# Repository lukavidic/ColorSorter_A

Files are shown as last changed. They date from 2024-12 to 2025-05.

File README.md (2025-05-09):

# 🎨 Color Sorter

## Projekat iz predmeta Mikrokontrolerski sistemi

**ColorSorter** je pametni sistem za automatsko razvrstavanje pločica po bojama. Projekat je razvijen u okviru predmeta *Mikrokontrolerski sistemi* i koristi:
- senzor boja
- servo motor za upravljanje mehanizmom sortiranja
- Wi-Fi modul za bežičnu komunikaciju

## Cilj projekta

Cilj je omogućiti **brzo, precizno i pametno sortiranje pločica** uz real-time komunikaciju i nadzor. Sistem je osmišljen tako da može raditi autonomno, kao i pod nadzorom korisnika putem aplikacije. Sve zahtjeve možete pogledati na **Wiki** stranici - [O projektu](https://github.com/lukavidic/ColorSorter_A/wiki/2.-O-projektu) kao i [dostupne i potrebne komponente](https://github.com/lukavidic/ColorSorter_A/wiki/3.-Dostupne-i-potrebne-komponente).

---

## Realizacija projekta

Razvoj sistema je tekao kroz sledeće faze:

1.  **Kreiranje električne šeme**
   
    Na samom početku kreirana je električna šema, koja prikazuje sve povezane komponente i njihovu funkcionalnu ulogu u realizaciji ovog projekta.
    Detalje možete pronaći na **Wiki** stranici – [Projektovanje električne šeme u alatu KiCAD](https://github.com/lukavidic/ColorSorter_A/wiki/4.-Projektovanje-elektri%C4%8Dne-%C5%A1eme-u-alatu-KiCAD).

2.  **Izrada PCB-a**
   
    Na osnovu električne šeme, dizajnirana je štampana ploča (PCB) koja omogućava stabilno napajanje i povezivanje svih perifernih komponenti.
    PCB sadrži:

      - Mikrokontroler PIC24FJ64GA702 kao centralnu upravljačku jedinicu

      - Pasivne komponente (otpornici, kondenzatori)
  
      - Regulatore napona
  
      - Konektore i pinove za povezivanje sa eksternim uređajima kao što su senzor boja, servo motor te WiFi modul
    
    Više o dizajnu ploče dostupno je na **Wiki** stranici – [Projektovanje PCB-a u alatu KiCAD](https://github.com/lukavidic/ColorSorter_A/wiki/4.-Projektovanje-elektri%C4%8Dne-%C5%A1eme-u-alatu-KiCAD).

3.  **Programiranje mikrokontrolera**
   
    Nakon hardverske realizacije, implementiran je kod za rad uređaja – uključujući očitavanje boja, kontrolu motora i Wi-Fi komunikaciju, čiju dokumentaciju kompletnog koda možete pronaći na **Wiki** stranici - [Programiranje mikrokontrolera](https://github.com/lukavidic/ColorSorter_A/wiki/6.-Programiranje-mikrokontrolera).

4. **Izrada aplikacije**

   Nakon uspješnog programiranja mikrokontrolerske pločice, pristupili smo razvoju desktop aplikacije koja omogućava nadzor i upravljanje procesom razvrstavanja boja. Aplikacija komunicira sa uređajem putem WiFi veze i omogućava korisniku da prati status sistema u realnom vremenu, šalje komande za pokretanje i resetovanje, te definiše pravila sortiranja po bojama. O zahtjevima aplikacije možete pogledati na **Wiki** stranici - [Firmware i aplikacija](https://github.com/lukavidic/ColorSorter_A/wiki/7.-Firmware-i-aplikacija).

5.  **Testiranje i kalibracija**
   
    Sistem je prolazio kroz više faza testiranja kako bi se obezbijedila tačnost u detekciji boja i pravilno sortiranje. Kratak pogled u testiranje komponenata možete pronaći na **Wiki** stranici - [Testiranje rada komponenata](https://github.com/lukavidic/ColorSorter_A/wiki/7.-Testiranje-rada-komponenata).

colorsorter

---

## Autori
- Ana Vulin  
- Anđela Savičić  
- Luka Zeljko

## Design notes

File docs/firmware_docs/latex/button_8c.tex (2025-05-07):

\doxysection{button/button.c File Reference}
\hypertarget{button_8c}{}\label{button_8c}\index{button/button.c@{button/button.c}}

Button module source file.  

{\ttfamily \#include "{}button.\+h"{}}\newline
{\ttfamily \#include "{}../led/led.\+h"{}}\newline
{\ttfamily \#include "{}../servo/servo.\+h"{}}\newline
{\ttfamily \#include "{}../color\+\_\+sensor/color\+\_\+sensor.\+h"{}}\newline
{\ttfamily \#include "{}../inc/inc.\+h"{}}\newline
\doxysubsubsection*{Functions}
\begin{DoxyCompactItemize}
\item 
void \mbox{\hyperlink{button_8c_a681470fea7c7eaa67094df3e5567a8f7}{button\+\_\+init}} ()
\begin{DoxyCompactList}\small\item\em Initializes the button and sets up interrupt configuration. \end{DoxyCompactList}\item 
void \mbox{\hyperlink{button_8c_aab3a22f4fca32e3600be53c5cd5cdc55}{init\+Prekidi}} ()
\begin{DoxyCompactList}\small\item\em Initializes interrupts for the button. \end{DoxyCompactList}\item 
void \mbox{\hyperlink{button_8c_a226557d5e42f7e29ddaff30606138459}{\+\_\+\+\_\+attribute\+\_\+\+\_\+}} ((interrupt, no\+\_\+auto\+\_\+psv))
\begin{DoxyCompactList}\small\item\em Interrupt service routine for I2\+C1 slave interrupt. \end{DoxyCompactList}\end{DoxyCompactItemize}
\doxysubsubsection*{Variables}
\begin{DoxyCompactItemize}
\item 
int \mbox{\hyperlink{button_8c_aac274e9c06b25faa040b6ba219fc2e75}{reset\+\_\+counter}} = 1
\item 
volatile int \mbox{\hyperlink{button_8c_a81abebcb507939407ceaeb9007b656bc}{press\+\_\+counter}} = 1
\end{DoxyCompactItemize}

\doxysubsection{Detailed Description}
Button module source file. 

File containing definitions of functions decleared in \doxylink{button_8h}{button.\+h} 

\doxysubsection{Function Documentation}
\Hypertarget{button_8c_a226557d5e42f7e29ddaff30606138459}\index{button.c@{button.c}!\_\_attribute\_\_@{\_\_attribute\_\_}}
\index{\_\_attribute\_\_@{\_\_attribute\_\_}!button.c@{button.c}}
\doxysubsubsection{\texorpdfstring{\_\_attribute\_\_()}{\_\_attribute\_\_()}}
{\footnotesize\ttfamily \label{button_8c_a226557d5e42f7e29ddaff30606138459} 
void \+\_\+\+\_\+attribute\+\_\+\+\_\+ (\begin{DoxyParamCaption}\item[{(interrupt, no\+\_\+auto\+\_\+psv)}]{}{}\end{DoxyParamCaption})}

Interrupt service routine for I2\+C1 slave interrupt. 

INT1 interrupt handler (button press).

This interrupt handler is called when an I2\+C1 slave mode interrupt occurs. It invokes the user-\/defined ISR set by the {\ttfamily i2c1\+\_\+driver\+\_\+set\+Slave\+I2c\+ISR} function. \Hypertarget{button_8c_a681470fea7c7eaa67094df3e5567a8f7}\index{button.c@{button.c}!button\_init@{button\_init}}
\index{button\_init@{button\_init}!button.c@{button.c}}
\doxysubsubsection{\texorpdfstring{button\_init()}{button\_init()}}
{\footnotesize\ttfamily \label{button_8c_a681470fea7c7eaa67094df3e5567a8f7} 
void button\+\_\+init (\begin{DoxyParamCaption}{}{}\end{DoxyParamCaption})}

Initializes the button and sets up interrupt configuration. 

This function configures pin RB5 as an input and calls the function to initialize interrupts. \Hypertarget{button_8c_aab3a22f4fca32e3600be53c5cd5cdc55}\index{button.c@{button.c}!initPrekidi@{initPrekidi}}
\index{initPrekidi@{initPrekidi}!button.c@{button.c}}
\doxysubsubsection{\texorpdfstring{initPrekidi()}{initPrekidi()}}
{\footnotesize\ttfamily \label{button_8c_aab3a22f4fca32e3600be53c5cd5cdc55} 
void init\+Prekidi (\begin{DoxyParamCaption}{}{}\end{DoxyParamCaption})}

Initializes interrupts for the button. 

This function sets up the parameters for INT1 interrupt, enables the interrupt on falling edge, and enables global interrupts. 

\doxysubsection{Variable Documentation}
\Hypertarget{button_8c_a81abebcb507939407ceaeb9007b656bc}\index{button.c@{button.c}!press\_counter@{press\_counter}}
\index{press\_counter@{press\_counter}!button.c@{button.c}}
\doxysubsubsection{\texorpdfstring{press\_counter}{press\_counter}}
{\footnotesize\ttfamily \label{button_8c_a81abebcb507939407ceaeb9007b656bc} 
volatile int press\+\_\+counter = 1}

\Hypertarget{button_8c_aac274e9c06b25faa040b6ba219fc2e75}\index{button.c@{button.c}!reset\_counter@{reset\_counter}}
\index{reset\_counter@{reset\_counter}!button.c@{button.c}}
\doxysubsubsection{\texorpdfstring{reset\_counter}{reset\_counter}}
{\footnotesize\ttfamily \label{button_8c_aac274e9c06b25faa040b6ba219fc2e75} 
int reset\+\_\+counter = 1}

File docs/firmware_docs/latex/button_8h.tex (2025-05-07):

\doxysection{button/button.h File Reference}
\hypertarget{button_8h}{}\label{button_8h}\index{button/button.h@{button/button.h}}

BUTTON header file.  

{\ttfamily \#include "{}../inc/inc.\+h"{}}\newline
\doxysubsubsection*{Functions}
\begin{DoxyCompactItemize}
\item 
void \mbox{\hyperlink{button_8h_a681470fea7c7eaa67094df3e5567a8f7}{button\+\_\+init}} ()
\begin{DoxyCompactList}\small\item\em Initializes the button and sets up interrupt configuration. \end{DoxyCompactList}\item 
void \mbox{\hyperlink{button_8h_aab3a22f4fca32e3600be53c5cd5cdc55}{init\+Prekidi}} ()
\begin{DoxyCompactList}\small\item\em Initializes interrupts for the button. \end{DoxyCompactList}\item 
void \mbox{\hyperlink{button_8h_a806ff639c7979669bd17a40fc3986611}{\+\_\+\+\_\+attribute\+\_\+\+\_\+}} ((interrupt, no\+\_\+auto\+\_\+psv)) \+\_\+\+INT1\+Interrupt(void)
\begin{DoxyCompactList}\small\item\em INT1 interrupt handler (button press). \end{DoxyCompactList}\end{DoxyCompactItemize}
\doxysubsubsection*{Variables}
\begin{DoxyCompactItemize}
\item 
volatile int \mbox{\hyperlink{button_8h_a81abebcb507939407ceaeb9007b656bc}{press\+\_\+counter}}
\item 
int \mbox{\hyperlink{button_8h_aac274e9c06b25faa040b6ba219fc2e75}{reset\+\_\+counter}}
\end{DoxyCompactItemize}

\doxysubsection{Detailed Description}
BUTTON header file. 

This file contains function definitions for BUTTON control 

\doxysubsection{Function Documentation}
\Hypertarget{button_8h_a806ff639c7979669bd17a40fc3986611}\index{button.h@{button.h}!\_\_attribute\_\_@{\_\_attribute\_\_}}
\index{\_\_attribute\_\_@{\_\_attribute\_\_}!button.h@{button.h}}
\doxysubsubsection{\texorpdfstring{\_\_attribute\_\_()}{\_\_attribute\_\_()}}
{\footnotesize\ttfamily \label{button_8h_a806ff639c7979669bd17a40fc3986611} 
void \+\_\+\+\_\+attribute\+\_\+\+\_\+ (\begin{DoxyParamCaption}\item[{(interrupt, no\+\_\+auto\+\_\+psv)}]{}{}\end{DoxyParamCaption})}

INT1 interrupt handler (button press). 

This function is called when the button connected to INT1 is pressed. It increments the press counter and toggles the system state (turns LED on/off, centers the servo, and sets RGB color) based on the number of presses.

INT1 interrupt handler (button press).

This interrupt handler is called when an I2\+C1 slave mode interrupt occurs. It invokes the user-\/defined ISR set by the {\ttfamily i2c1\+\_\+driver\+\_\+set\+Slave\+I2c\+ISR} function.

INT1 interrupt handler (button press).

Interrupt service routine for I2\+C1 slave interrupt.

This interrupt handler is called when an I2\+C1 master mode interrupt occurs. It invokes the user-\/defined ISR set by the {\ttfamily i2c1\+\_\+driver\+\_\+set\+Master\+I2c\+ISR} function.

This interrupt handler is called when an I2\+C1 slave mode interrupt occurs. It invokes the user-\/defined ISR set by the {\ttfamily i2c1\+\_\+driver\+\_\+set\+Slave\+I2c\+ISR} function. \Hypertarget{button_8h_a681470fea7c7eaa67094df3e5567a8f7}\index{button.h@{button.h}!button\_init@{button\_init}}
\index{button\_init@{button\_init}!button.h@{button.h}}
\doxysubsubsection{\texorpdfstring{button\_init()}{button\_init()}}
{\footnotesize\ttfamily \label{button_8h_a681470fea7c7eaa67094df3e5567a8f7} 
void button\+\_\+init (\begin{DoxyParamCaption}{}{}\end{DoxyParamCaption})}

Initializes the button and sets up interrupt configuration. 

This function configures pin RB5 as an input and calls the function to initialize interrupts. \Hypertarget{button_8h_aab3a22f4fca32e3600be53c5cd5cdc55}\index{button.h@{button.h}!initPrekidi@{initPrekidi}}
\index{initPrekidi@{initPrekidi}!button.h@{button.h}}
\doxysubsubsection{\texorpdfstring{initPrekidi()}{initPrekidi()}}
{\footnotesize\ttfamily \label{button_8h_aab3a22f4fca32e3600be53c5cd5cdc55} 
void init\+Prekidi (\begin{DoxyParamCaption}{}{}\end{DoxyParamCaption})}

Initializes interrupts for the button. 

This function sets up the parameters for INT1 interrupt, enables the interrupt on falling edge, and enables global interrupts. 

\doxysubsection{Variable Documentation}
\Hypertarget{button_8h_a81abebcb507939407ceaeb9007b656bc}\index{button.h@{button.h}!press\_counter@{press\_counter}}
\index{press\_counter@{press\_counter}!button.h@{button.h}}
\doxysubsubsection{\texorpdfstring{press\_counter}{press\_counter}}
{\footnotesize\ttfamily \label{button_8h_a81abebcb507939407ceaeb9007b656bc} 
volatile int press\+\_\+counter\hspace{0.3cm}{\ttfamily [extern]}}

\Hypertarget{button_8h_aac274e9c06b25faa040b6ba219fc2e75}\index{button.h@{button.h}!reset\_counter@{reset\_counter}}
\index{reset\_counter@{reset\_counter}!button.h@{button.h}}
\doxysubsubsection{\texorpdfstring{reset\_counter}{reset\_counter}}
{\footnotesize\ttfamily \label{button_8h_aac274e9c06b25faa040b6ba219fc2e75} 
int reset\+\_\+counter\hspace{0.3cm}{\ttfamily [extern]}}

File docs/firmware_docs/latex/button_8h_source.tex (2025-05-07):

\doxysection{button.\+h}
\hypertarget{button_8h_source}{}\label{button_8h_source}\index{button/button.h@{button/button.h}}
\mbox{\hyperlink{button_8h}{Go to the documentation of this file.}}
\begin{DoxyCode}{0}
\DoxyCodeLine{00001\ }
\DoxyCodeLine{00007\ \textcolor{preprocessor}{\#ifndef\ BUTTON\_H}}
\DoxyCodeLine{00008\ }
\DoxyCodeLine{00009\ \textcolor{preprocessor}{\#define\ BUTTON\_H}}
\DoxyCodeLine{00010\ }
\DoxyCodeLine{00011\ \textcolor{preprocessor}{\#include\ "{}\mbox{\hyperlink{inc_8h}{../inc/inc.h}}"{}}}
\DoxyCodeLine{00012\ }
\DoxyCodeLine{00013\ \textcolor{comment}{//\ External\ variable\ that\ counts\ button\ presses.}}
\DoxyCodeLine{00014\ \textcolor{keyword}{extern}\ \textcolor{keyword}{volatile}\ \textcolor{keywordtype}{int}\ \mbox{\hyperlink{button_8c_a81abebcb507939407ceaeb9007b656bc}{press\_counter}};}
\DoxyCodeLine{00015\ }
\DoxyCodeLine{00016\ \textcolor{comment}{//\ External\ variable\ that\ controls\ system\ reset.}}
\DoxyCodeLine{00017\ \textcolor{keyword}{extern}\ \textcolor{keywordtype}{int}\ \mbox{\hyperlink{button_8c_aac274e9c06b25faa040b6ba219fc2e75}{reset\_counter}};}
\DoxyCodeLine{00018\ }
\DoxyCodeLine{00025\ \textcolor{keywordtype}{void}\ \mbox{\hyperlink{button_8h_a681470fea7c7eaa67094df3e5567a8f7}{button\_init}}();}
\DoxyCodeLine{00032\ \textcolor{keywordtype}{void}\ \mbox{\hyperlink{button_8h_aab3a22f4fca32e3600be53c5cd5cdc55}{initPrekidi}}();}
\DoxyCodeLine{00040\ \textcolor{keywordtype}{void}\ \mbox{\hyperlink{button_8h_a806ff639c7979669bd17a40fc3986611}{\_\_attribute\_\_}}((interrupt,\ no\_auto\_psv))\ \_INT1Interrupt(\textcolor{keywordtype}{void});}
\DoxyCodeLine{00041\ }
\DoxyCodeLine{00042\ \textcolor{preprocessor}{\#endif}}

\end{DoxyCode}

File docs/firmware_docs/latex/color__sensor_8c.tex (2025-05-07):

\doxysection{color\+\_\+sensor/color\+\_\+sensor.c File Reference}
\hypertarget{color__sensor_8c}{}\label{color__sensor_8c}\index{color\_sensor/color\_sensor.c@{color\_sensor/color\_sensor.c}}

\doxylink{structColor}{Color} sensor module source file.  

{\ttfamily \#include "{}color\+\_\+sensor.\+h"{}}\newline
{\ttfamily \#include "{}../led/led.\+h"{}}\newline
{\ttfamily \#include "{}../inc/inc.\+h"{}}\newline
{\ttfamily \#include "{}../color\+\_\+sensor/i2c\+\_\+simple\+\_\+master.\+h"{}}\newline
{\ttfamily \#include "{}../color\+\_\+sensor/i2c\+\_\+master.\+h"{}}\newline
{\ttfamily \#include "{}xc.\+h"{}}\newline
{\ttfamily \#include $<$stdio.\+h$>$}\newline
{\ttfamily \#include $<$math.\+h$>$}\newline
{\ttfamily \#include $<$stdint.\+h$>$}\newline
\doxysubsubsection*{Data Structures}
\begin{DoxyCompactItemize}
\item 
struct \mbox{\hyperlink{structColor}{Color}}
\end{DoxyCompactItemize}
\doxysubsubsection*{Functions}
\begin{DoxyCompactItemize}
\item 
char \texorpdfstring{$\ast$}{*} \mbox{\hyperlink{color__sensor_8c_a9fa725f2640f9efd473fc7a5f2de92dc}{detect\+\_\+color}} ()
\begin{DoxyCompactList}\small\item\em Detects the color based on sensor readings. \end{DoxyCompactList}\item 
void \mbox{\hyperlink{color__sensor_8c_a30da27c967c427811646a5a6f66f495f}{WS2812\+\_\+\+Send\+\_\+\+Byte}} (uint8\+\_\+t byte)
\begin{DoxyCompactList}\small\item\em Sends a single byte of data to the WS2812 RGB LED. \end{DoxyCompactList}\item 
void \mbox{\hyperlink{color__sensor_8c_a938d9076304a30229d0cff9510c6b0de}{WS2812\+\_\+\+Set\+Color}} (uint8\+\_\+t red, uint8\+\_\+t green, uint8\+\_\+t blue)
\begin{DoxyCompactList}\small\item\em Sets the color of the WS2812 RGB LED. \end{DoxyCompactList}\item 
uint16\+\_\+t \mbox{\hyperlink{color__sensor_8c_a053b418e905501066d9d10d143bde94a}{VEML3328\+\_\+read\+Config}} (uint16\+\_\+t r)
\begin{DoxyCompactList}\small\item\em Reads the configuration register of the VEML3328 color sensor. \end{DoxyCompactList}\item 
char \texorpdfstring{$\ast$}{*} \mbox{\hyperlink{color__sensor_8c_a9bafee1f49378aa30e64fec0a857a6b4}{read\+\_\+colors}} ()
\begin{DoxyCompactList}\small\item\em Reads the color data from the VEML3328 sensor and detects the closest matching color. \end{DoxyCompactList}\item 
float \mbox{\hyperlink{color__sensor_8c_a1e56582afed332aa1260fc2785c7777e}{color\+\_\+distance}} (uint16\+\_\+t r1, uint16\+\_\+t g1, uint16\+\_\+t b1, uint16\+\_\+t r2, uint16\+\_\+t g2, uint16\+\_\+t b2)
\begin{DoxyCompactList}\small\item\em Calculates the Euclidean distance between two RGB colors. \end{DoxyCompactList}\end{DoxyCompactItemize}
\doxysubsubsection*{Variables}
\begin{DoxyCompactItemize}
\item 
uint16\+\_\+t \mbox{\hyperlink{color__sensor_8c_aa4dbd934c1f532f057c7016fc46c17d8}{sensor\+\_\+value\+\_\+clear}}
\item 
uint16\+\_\+t \mbox{\hyperlink{color__sensor_8c_a40af162a563cdee76bbc32221b1700f6}{sensor\+\_\+value\+\_\+red}}
\item 
uint16\+\_\+t \mbox{\hyperlink{color__sensor_8c_ad72744df2efce619a151cdd8f6a28aeb}{sensor\+\_\+value\+\_\+green}}
\item 
uint16\+\_\+t \mbox{\hyperlink{color__sensor_8c_ac8d4dfdb5c4ec07d415bb45a1f8e4d00}{sensor\+\_\+value\+\_\+blue}}
\item 
const \mbox{\hyperlink{structColor}{Color}} \mbox{\hyperlink{color__sensor_8c_a0e450f8f554764fb50c75197d16a7c9f}{colors}} \mbox{[}$\,$\mbox{]}
\end{DoxyCompactItemize}

\doxysubsection{Detailed Description}
\doxylink{structColor}{Color} sensor module source file. 

This file contains definitions of functions decleared in \doxylink{color__sensor_8h}{color\+\_\+sensor.\+h} 

\doxysubsection{Function Documentation}
\Hypertarget{color__sensor_8c_a1e56582afed332aa1260fc2785c7777e}\index{color\_sensor.c@{color\_sensor.c}!color\_distance@{color\_distance}}
\index{color\_distance@{color\_distance}!color\_sensor.c@{color\_sensor.c}}
\doxysubsubsection{\texorpdfstring{color\_distance()}{color\_distance()}}
{\footnotesize\ttfamily \label{color__sensor_8c_a1e56582afed332aa1260fc2785c7777e} 
float color\+\_\+distance (\begin{DoxyParamCaption}\item[{uint16\+\_\+t}]{r1}{, }\item[{uint16\+\_\+t}]{g1}{, }\item[{uint16\+\_\+t}]{b1}{, }\item[{uint16\+\_\+t}]{r2}{, }\item[{uint16\+\_\+t}]{g2}{, }\item[{uint16\+\_\+t}]{b2}{}\end{DoxyParamCaption})}

Calculates the Euclidean distance between two RGB colors. 

This function calculates the Euclidean distance between two colors in the RGB color space. The smaller the distance, the closer the two colors are.

\begin{DoxyParams}{Parameters}
{\em r1} & The red component of the first color. \\
\hline
{\em g1} & The green component of the first color. \\
\hline
{\em b1} & The blue component of the first color. \\
\hline
{\em r2} & The red component of the second color. \\
\hline
{\em g2} & The green component of the second color. \\
\hline
{\em b2} & The blue component of the second color.\\
\hline
\end{DoxyParams}
\begin{DoxyReturn}{Returns}
The Euclidean distance between the two colors. 
\end{DoxyReturn}
\Hypertarget{color__sensor_8c_a9fa725f2640f9efd473fc7a5f2de92dc}\index{color\_sensor.c@{color\_sensor.c}!detect\_color@{detect\_color}}
\index{detect\_color@{detect\_color}!color\_sensor.c@{color\_sensor.c}}
\doxysubsubsection{\texorpdfstring{detect\_color()}{detect\_color()}}
{\footnotesize\ttfamily \label{color__sensor_8c_a9fa725f2640f9efd473fc7a5f2de92dc} 
char \texorpdfstring{$\ast$}{*} detect\+\_\+color (\begin{DoxyParamCaption}{}{}\end{DoxyParamCaption})}

Detects the color based on sensor readings. 

This function compares the RGB values of the detected color from the sensor to a list of predefined colors and calculates the Euclidean distance to find the closest match.

\begin{DoxyReturn}{Returns}
The name of the closest matching color as a string. 
\end{DoxyReturn}
\Hypertarget{color__sensor_8c_a9bafee1f49378aa30e64fec0a857a6b4}\index{color\_sensor.c@{color\_sensor.c}!read\_colors@{read\_colors}}
\index{read\_colors@{read\_colors}!color\_sensor.c@{color\_sensor.c}}
\doxysubsubsection{\texorpdfstring{read\_colors()}{read\_colors()}}
{\footnotesize\ttfamily \label{color__sensor_8c_a9bafee1f49378aa30e64fec0a857a6b4} 
char \texorpdfstring{$\ast$}{*} read\+\_\+colors (\begin{DoxyParamCaption}{}{}\end{DoxyParamCaption})}

Reads the color data from the VEML3328 sensor and detects the closest matching color. 

This function collects multiple color samples (red, green, blue) from the VEML3328 sensor, averages the readings, and uses the {\ttfamily detect\+\_\+color} function to identify the closest matching color.

\begin{DoxyReturn}{Returns}
The name of the closest matching color as a string. 
\end{DoxyReturn}
\Hypertarget{color__sensor_8c_a053b418e905501066d9d10d143bde94a}\index{color\_sensor.c@{color\_sensor.c}!VEML3328\_readConfig@{VEML3328\_readConfig}}
\index{VEML3328\_readConfig@{VEML3328\_readConfig}!color\_sensor.c@{color\_sensor.c}}
\doxysubsubsection{\texorpdfstring{VEML3328\_readConfig()}{VEML3328\_readConfig()}}
{\footnotesize\ttfamily \label{color__sensor_8c_a053b418e905501066d9d10d143bde94a} 
uint16\+\_\+t VEML3328\+\_\+read\+Config (\begin{DoxyParamCaption}\item[{uint16\+\_\+t}]{r}{}\end{DoxyParamCaption})}

Reads the configuration register of the VEML3328 color sensor. 

This function reads a 16-\/bit value from a specified register on the VEML3328 sensor over I2C.

\begin{DoxyParams}{Parameters}
{\em r} & The register address to be read.\\
\hline
\end{DoxyParams}
\begin{DoxyReturn}{Returns}
The 16-\/bit value read from the specified register. 
\end{DoxyReturn}
\Hypertarget{color__sensor_8c_a30da27c967c427811646a5a6f66f495f}\index{color\_sensor.c@{color\_sensor.c}!WS2812\_Send\_Byte@{WS2812\_Send\_Byte}}
\index{WS2812\_Send\_Byte@{WS2812\_Send\_Byte}!color\_sensor.c@{color\_sensor.c}}
\doxysubsubsection{\texorpdfstring{WS2812\_Send\_Byte()}{WS2812\_Send\_Byte()}}
{\footnotesize\ttfamily \label{color__sensor_8c_a30da27c967c427811646a5a6f66f495f} 
void WS2812\+\_\+\+Send\+\_\+\+Byte (\begin{DoxyParamCaption}\item[{uint8\+\_\+t}]{byte}{}\end{DoxyParamCaption})}

Sends a single byte of data to the WS2812 RGB LED. 

This function sends a byte of data to the WS2812 LED over SPI, with each bit corresponding to a part of the LED data stream.

\begin{DoxyParams}{Parameters}
{\em byte} & The byte to be sent to the WS2812. \\
\hline
\end{DoxyParams}
\Hypertarget{color__sensor_8c_a938d9076304a30229d0cff9510c6b0de}\index{color\_sensor.c@{color\_sensor.c}!WS2812\_SetColor@{WS2812\_SetColor}}
\index{WS2812\_SetColor@{WS2812\_SetColor}!color\_sensor.c@{color\_sensor.c}}
\doxysubsubsection{\texorpdfstring{WS2812\_SetColor()}{WS2812\_SetColor()}}
{\footnotesize\ttfamily \label{color__sensor_8c_a938d9076304a30229d0cff9510c6b0de} 
void WS2812\+\_\+\+Set\+Color (\begin{DoxyParamCaption}\item[{uint8\+\_\+t}]{red}{, }\item[{uint8\+\_\+t}]{green}{, }\item[{uint8\+\_\+t}]{blue}{}\end{DoxyParamCaption})}

Sets the color of the WS2812 RGB LED. 

This function sends the color values for red, green, and blue to the WS2812 LED using SPI.

\begin{DoxyParams}{Parameters}
{\em red} & The red component of the color (0-\/255). \\
\hline
{\em green} & The green component of the color (0-\/255). \\
\hline
{\em blue} & The blue component of the color (0-\/255). \\
\hline
\end{DoxyParams}

\doxysubsection{Variable Documentation}
\Hypertarget{color__sensor_8c_a0e450f8f554764fb50c75197d16a7c9f}\index{color\_sensor.c@{color\_sensor.c}!colors@{colors}}
\index{colors@{colors}!color\_sensor.c@{color\_sensor.c}}
\doxysubsubsection{\texorpdfstring{colors}{colors}}
{\footnotesize\ttfamily \label{color__sensor_8c_a0e450f8f554764fb50c75197d16a7c9f} 
const \mbox{\hyperlink{structColor}{Color}} colors\mbox{[}$\,$\mbox{]}}

{\bfseries Initial value\+:}
\begin{DoxyCode}{0}
\DoxyCodeLine{=\ \{}
\DoxyCodeLine{\ \ \ \ \{\textcolor{stringliteral}{"{}ZELENA"{}},\ \ \ \ \ 6500,\ 29000,\ 28000\},}
\DoxyCodeLine{\ \ \ \ \{\textcolor{stringliteral}{"{}PLAVA"{}},\ \ \ \ \ \ 13800,\ 45100,\ 65500\},}
\DoxyCodeLine{\ \ \ \ \{\textcolor{stringliteral}{"{}CRVENA"{}},\ \ \ \ 40500,\ 21800,\ 24400\},}
\DoxyCodeLine{\ \ \ \ \{\textcolor{stringliteral}{"{}ZUTA"{}},\ \ \ \ \ \ 45000,\ 65535,\ 40500\},}
\DoxyCodeLine{\ \ \ \ \{\textcolor{stringliteral}{"{}NARANDZASTA"{}},40700,\ 18800,\ 14500\},}
\DoxyCodeLine{\ \ \ \ \{\textcolor{stringliteral}{"{}ROZA"{}},\ \ \ \ \ \ 34100,\ 20200,\ 29800\},}
\DoxyCodeLine{\ \ \ \ \{\textcolor{stringliteral}{"{}CRNA"{}},\ \ \ \ \ \ \ 6000,\ 12300,\ 16500\},}
\DoxyCodeLine{\ \ \ \ \{\textcolor{stringliteral}{"{}BIJELA"{}},\ \ \ \ 48900,\ 65535,\ 65535\},}
\DoxyCodeLine{\ \ \ \ \{\textcolor{stringliteral}{"{}NO"{}},\ \ \ \ \ \ \ \ \ 15700,\ \ 19000,\ \ 21000\},}
\DoxyCodeLine{\ \ \ \ \{\textcolor{stringliteral}{"{}OCRNA"{}},\ \ \ \ \ \ 7800,11800,16000\},\ }
\DoxyCodeLine{\ \ \ \ \{\textcolor{stringliteral}{"{}OBIJELA"{}},\ \ \ \ \ \ 30800,45900,63900\}\ }
\DoxyCodeLine{\}}

\end{DoxyCode}
\Hypertarget{color__sensor_8c_ac8d4dfdb5c4ec07d415bb45a1f8e4d00}\index{color\_sensor.c@{color\_sensor.c}!sensor\_value\_blue@{sensor\_value\_blue}}
\index{sensor\_value\_blue@{sensor\_value\_blue}!color\_sensor.c@{color\_sensor.c}}
\doxysubsubsection{\texorpdfstring{sensor\_value\_blue}{sensor\_value\_blue}}
{\footnotesize\ttfamily \label{color__sensor_8c_ac8d4dfdb5c4ec07d415bb45a1f8e4d00} 
uint16\+\_\+t sensor\+\_\+value\+\_\+blue}

\Hypertarget{color__sensor_8c_aa4dbd934c1f532f057c7016fc46c17d8}\index{color\_sensor.c@{color\_sensor.c}!sensor\_value\_clear@{sensor\_value\_clear}}
\index{sensor\_value\_clear@{sensor\_value\_clear}!color\_sensor.c@{color\_sensor.c}}
\doxysubsubsection{\texorpdfstring{sensor\_value\_clear}{sensor\_value\_clear}}
{\footnotesize\ttfamily \label{color__sensor_8c_aa4dbd934c1f532f057c7016fc46c17d8} 
uint16\+\_\+t sensor\+\_\+value\+\_\+clear}

\Hypertarget{color__sensor_8c_ad72744df2efce619a151cdd8f6a28aeb}\index{color\_sensor.c@{color\_sensor.c}!sensor\_value\_green@{sensor\_value\_green}}
\index{sensor\_value\_green@{sensor\_value\_green}!color\_sensor.c@{color\_sensor.c}}
\doxysubsubsection{\texorpdfstring{sensor\_value\_green}{sensor\_value\_green}}
{\footnotesize\ttfamily \label{color__sensor_8c_ad72744df2efce619a151cdd8f6a28aeb} 
uint16\+\_\+t sensor\+\_\+value\+\_\+green}

\Hypertarget{color__sensor_8c_a40af162a563cdee76bbc32221b1700f6}\index{color\_sensor.c@{color\_sensor.c}!sensor\_value\_red@{sensor\_value\_red}}
\index{sensor\_value\_red@{sensor\_value\_red}!color\_sensor.c@{color\_sensor.c}}
\doxysubsubsection{\texorpdfstring{sensor\_value\_red}{sensor\_value\_red}}
{\footnotesize\ttfamily \label{color__sensor_8c_a40af162a563cdee76bbc32221b1700f6} 
uint16\+\_\+t sensor\+\_\+value\+\_\+red}

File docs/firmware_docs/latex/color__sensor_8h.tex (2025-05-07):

\doxysection{color\+\_\+sensor/color\+\_\+sensor.h File Reference}
\hypertarget{color__sensor_8h}{}\label{color__sensor_8h}\index{color\_sensor/color\_sensor.h@{color\_sensor/color\_sensor.h}}

\doxylink{structColor}{Color} sensor module header file.  

{\ttfamily \#include "{}../inc/inc.\+h"{}}\newline
\doxysubsubsection*{Functions}
\begin{DoxyCompactItemize}
\item 
char \texorpdfstring{$\ast$}{*} \mbox{\hyperlink{color__sensor_8h_a9bafee1f49378aa30e64fec0a857a6b4}{read\+\_\+colors}} ()
\begin{DoxyCompactList}\small\item\em Reads the color data from the VEML3328 sensor and detects the closest matching color. \end{DoxyCompactList}\item 
char \texorpdfstring{$\ast$}{*} \mbox{\hyperlink{color__sensor_8h_a9fa725f2640f9efd473fc7a5f2de92dc}{detect\+\_\+color}} ()
\begin{DoxyCompactList}\small\item\em Detects the color based on sensor readings. \end{DoxyCompactList}\item 
float \mbox{\hyperlink{color__sensor_8h_a1e56582afed332aa1260fc2785c7777e}{color\+\_\+distance}} (uint16\+\_\+t r1, uint16\+\_\+t g1, uint16\+\_\+t b1, uint16\+\_\+t r2, uint16\+\_\+t g2, uint16\+\_\+t b2)
\begin{DoxyCompactList}\small\item\em Calculates the Euclidean distance between two RGB colors. \end{DoxyCompactList}\item 
void \mbox{\hyperlink{color__sensor_8h_a30da27c967c427811646a5a6f66f495f}{WS2812\+\_\+\+Send\+\_\+\+Byte}} (uint8\+\_\+t byte)
\begin{DoxyCompactList}\small\item\em Sends a single byte of data to the WS2812 RGB LED. \end{DoxyCompactList}\item 
void \mbox{\hyperlink{color__sensor_8h_a938d9076304a30229d0cff9510c6b0de}{WS2812\+\_\+\+Set\+Color}} (uint8\+\_\+t red, uint8\+\_\+t green, uint8\+\_\+t blue)
\begin{DoxyCompactList}\small\item\em Sets the color of the WS2812 RGB LED. \end{DoxyCompactList}\item 
uint16\+\_\+t \mbox{\hyperlink{color__sensor_8h_a053b418e905501066d9d10d143bde94a}{VEML3328\+\_\+read\+Config}} (uint16\+\_\+t r)
\begin{DoxyCompactList}\small\item\em Reads the configuration register of the VEML3328 color sensor. \end{DoxyCompactList}\end{DoxyCompactItemize}

\doxysubsection{Detailed Description}
\doxylink{structColor}{Color} sensor module header file. 

\doxysubsection{Function Documentation}
\Hypertarget{color__sensor_8h_a1e56582afed332aa1260fc2785c7777e}\index{color\_sensor.h@{color\_sensor.h}!color\_distance@{color\_distance}}
\index{color\_distance@{color\_distance}!color\_sensor.h@{color\_sensor.h}}
\doxysubsubsection{\texorpdfstring{color\_distance()}{color\_distance()}}
{\footnotesize\ttfamily \label{color__sensor_8h_a1e56582afed332aa1260fc2785c7777e} 
float color\+\_\+distance (\begin{DoxyParamCaption}\item[{uint16\+\_\+t}]{r1}{, }\item[{uint16\+\_\+t}]{g1}{, }\item[{uint16\+\_\+t}]{b1}{, }\item[{uint16\+\_\+t}]{r2}{, }\item[{uint16\+\_\+t}]{g2}{, }\item[{uint16\+\_\+t}]{b2}{}\end{DoxyParamCaption})}

Calculates the Euclidean distance between two RGB colors. 

This function calculates the Euclidean distance between two colors in the RGB color space. The smaller the distance, the closer the two colors are.

\begin{DoxyParams}{Parameters}
{\em r1} & The red component of the first color. \\
\hline
{\em g1} & The green component of the first color. \\
\hline
{\em b1} & The blue component of the first color. \\
\hline
{\em r2} & The red component of the second color. \\
\hline
{\em g2} & The green component of the second color. \\
\hline
{\em b2} & The blue component of the second color.\\
\hline
\end{DoxyParams}
\begin{DoxyReturn}{Returns}
The Euclidean distance between the two colors. 
\end{DoxyReturn}
\Hypertarget{color__sensor_8h_a9fa725f2640f9efd473fc7a5f2de92dc}\index{color\_sensor.h@{color\_sensor.h}!detect\_color@{detect\_color}}
\index{detect\_color@{detect\_color}!color\_sensor.h@{color\_sensor.h}}
\doxysubsubsection{\texorpdfstring{detect\_color()}{detect\_color()}}
{\footnotesize\ttfamily \label{color__sensor_8h_a9fa725f2640f9efd473fc7a5f2de92dc} 
char \texorpdfstring{$\ast$}{*} detect\+\_\+color (\begin{DoxyParamCaption}{}{}\end{DoxyParamCaption})}

Detects the color based on sensor readings. 

This function compares the RGB values of the detected color from the sensor to a list of predefined colors and calculates the Euclidean distance to find the closest match.

\begin{DoxyReturn}{Returns}
The name of the closest matching color as a string. 
\end{DoxyReturn}
\Hypertarget{color__sensor_8h_a9bafee1f49378aa30e64fec0a857a6b4}\index{color\_sensor.h@{color\_sensor.h}!read\_colors@{read\_colors}}
\index{read\_colors@{read\_colors}!color\_sensor.h@{color\_sensor.h}}
\doxysubsubsection{\texorpdfstring{read\_colors()}{read\_colors()}}
{\footnotesize\ttfamily \label{color__sensor_8h_a9bafee1f49378aa30e64fec0a857a6b4} 
char \texorpdfstring{$\ast$}{*} read\+\_\+colors (\begin{DoxyParamCaption}{}{}\end{DoxyParamCaption})}

Reads the color data from the VEML3328 sensor and detects the closest matching color. 

This function collects multiple color samples (red, green, blue) from the VEML3328 sensor, averages the readings, and uses the {\ttfamily detect\+\_\+color} function to identify the closest matching color.

\begin{DoxyReturn}{Returns}
The name of the closest matching color as a string. 
\end{DoxyReturn}
\Hypertarget{color__sensor_8h_a053b418e905501066d9d10d143bde94a}\index{color\_sensor.h@{color\_sensor.h}!VEML3328\_readConfig@{VEML3328\_readConfig}}
\index{VEML3328\_readConfig@{VEML3328\_readConfig}!color\_sensor.h@{color\_sensor.h}}
\doxysubsubsection{\texorpdfstring{VEML3328\_readConfig()}{VEML3328\_readConfig()}}
{\footnotesize\ttfamily \label{color__sensor_8h_a053b418e905501066d9d10d143bde94a} 
uint16\+\_\+t VEML3328\+\_\+read\+Config (\begin{DoxyParamCaption}\item[{uint16\+\_\+t}]{r}{}\end{DoxyParamCaption})}

Reads the configuration register of the VEML3328 color sensor. 

This function reads a 16-\/bit value from a specified register on the VEML3328 sensor over I2C.

\begin{DoxyParams}{Parameters}
{\em r} & The register address to be read.\\
\hline
\end{DoxyParams}
\begin{DoxyReturn}{Returns}
The 16-\/bit value read from the specified register. 
\end{DoxyReturn}
\Hypertarget{color__sensor_8h_a30da27c967c427811646a5a6f66f495f}\index{color\_sensor.h@{color\_sensor.h}!WS2812\_Send\_Byte@{WS2812\_Send\_Byte}}
\index{WS2812\_Send\_Byte@{WS2812\_Send\_Byte}!color\_sensor.h@{color\_sensor.h}}
\doxysubsubsection{\texorpdfstring{WS2812\_Send\_Byte()}{WS2812\_Send\_Byte()}}
{\footnotesize\ttfamily \label{color__sensor_8h_a30da27c967c427811646a5a6f66f495f} 
void WS2812\+\_\+\+Send\+\_\+\+Byte (\begin{DoxyParamCaption}\item[{uint8\+\_\+t}]{byte}{}\end{DoxyParamCaption})}

Sends a single byte of data to the WS2812 RGB LED. 

This function sends a byte of data to the WS2812 LED over SPI, with each bit corresponding to a part of the LED data stream.

\begin{DoxyParams}{Parameters}
{\em byte} & The byte to be sent to the WS2812. \\
\hline
\end{DoxyParams}
\Hypertarget{color__sensor_8h_a938d9076304a30229d0cff9510c6b0de}\index{color\_sensor.h@{color\_sensor.h}!WS2812\_SetColor@{WS2812\_SetColor}}
\index{WS2812\_SetColor@{WS2812\_SetColor}!color\_sensor.h@{color\_sensor.h}}
\doxysubsubsection{\texorpdfstring{WS2812\_SetColor()}{WS2812\_SetColor()}}
{\footnotesize\ttfamily \label{color__sensor_8h_a938d9076304a30229d0cff9510c6b0de} 
void WS2812\+\_\+\+Set\+Color (\begin{DoxyParamCaption}\item[{uint8\+\_\+t}]{red}{, }\item[{uint8\+\_\+t}]{green}{, }\item[{uint8\+\_\+t}]{blue}{}\end{DoxyParamCaption})}

Sets the color of the WS2812 RGB LED. 

This function sends the color values for red, green, and blue to the WS2812 LED using SPI.

\begin{DoxyParams}{Parameters}
{\em red} & The red component of the color (0-\/255). \\
\hline
{\em green} & The green component of the color (0-\/255). \\
\hline
{\em blue} & The blue component of the color (0-\/255). \\
\hline
\end{DoxyParams}

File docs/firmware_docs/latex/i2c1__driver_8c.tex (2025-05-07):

\doxysection{color\+\_\+sensor/i2c1\+\_\+driver.c File Reference}
\hypertarget{i2c1__driver_8c}{}\label{i2c1__driver_8c}\index{color\_sensor/i2c1\_driver.c@{color\_sensor/i2c1\_driver.c}}

I2C driver source file.  

{\ttfamily \#include $<$stdio.\+h$>$}\newline
{\ttfamily \#include $<$stdint.\+h$>$}\newline
{\ttfamily \#include $<$stdbool.\+h$>$}\newline
{\ttfamily \#include "{}i2c1\+\_\+driver.\+h"{}}\newline
{\ttfamily \#include "{}../inc/inc.\+h"{}}\newline
{\ttfamily \#include $<$xc.\+h$>$}\newline
{\ttfamily \#include $<$libpic30.\+h$>$}\newline
\doxysubsubsection*{Functions}
\begin{DoxyCompactItemize}
\item 
void \mbox{\hyperlink{i2c1__driver_8c_aff5fb84305b4e5655721c950a3488196}{i2c1\+\_\+driver\+\_\+close}} (void)
\begin{DoxyCompactList}\small\item\em Disables the I2\+C1 peripheral by clearing the enable bit. \end{DoxyCompactList}\item 
void \mbox{\hyperlink{i2c1__driver_8c_a8ef15a19099711e8ee10fd31a7d7b847}{i2c1\+\_\+enable\+IRQ}} (void)
\begin{DoxyCompactList}\small\item\em Enables the I2\+C1 master and slave interrupt sources. \end{DoxyCompactList}\item 
bool \mbox{\hyperlink{i2c1__driver_8c_a3a562d793c89fe5f86c8954605041f1f}{i2c1\+\_\+\+IRQis\+Enabled}} (void)
\begin{DoxyCompactList}\small\item\em Checks whether I2\+C1 interrupts are currently enabled. \end{DoxyCompactList}\item 
void \mbox{\hyperlink{i2c1__driver_8c_ad88ed6deb0c925a79b507f0eced17c38}{i2c1\+\_\+disable\+IRQ}} (void)
\begin{DoxyCompactList}\small\item\em Disables the I2\+C1 master and slave interrupt sources. \end{DoxyCompactList}\item 
void \mbox{\hyperlink{i2c1__driver_8c_a33f284f52c97edb7125db041f382b98e}{i2c1\+\_\+clear\+IRQ}} (void)
\begin{DoxyCompactList}\small\item\em Clears the I2\+C1 interrupt flags. \end{DoxyCompactList}\item 
void \mbox{\hyperlink{i2c1__driver_8c_a733a1bea54d71551298a6780208796c9}{i2c1\+\_\+set\+IRQ}} (void)
\begin{DoxyCompactList}\small\item\em Sets the I2\+C1 interrupt flags. \end{DoxyCompactList}\item 
void \mbox{\hyperlink{i2c1__driver_8c_abac55eee70c770587d584181a98e1f96}{i2c1\+\_\+wait\+For\+Event}} (uint16\+\_\+t \texorpdfstring{$\ast$}{*}timeout)
\begin{DoxyCompactList}\small\item\em Waits for an I2\+C1 interrupt event with an optional timeout. \end{DoxyCompactList}\item 
bool \mbox{\hyperlink{i2c1__driver_8c_a73e12d1ac2f9ed036a413a4ec4973512}{i2c1\+\_\+driver\+\_\+driver\+\_\+open}} (void)
\begin{DoxyCompactList}\small\item\em Opens the I2\+C1 driver and initializes the hardware. \end{DoxyCompactList}\item 
bool \mbox{\hyperlink{i2c1__driver_8c_a0f9e55c5736c1b1fc31d3055093bf997}{i2c1\+\_\+driver\+\_\+init\+Slave\+Hardware}} (void)
\begin{DoxyCompactList}\small\item\em Initializes the I2\+C1 hardware in slave mode. \end{DoxyCompactList}\item 
void \mbox{\hyperlink{i2c1__driver_8c_a3291584a36361a8b886a5565a0897474}{i2c1\+\_\+driver\+\_\+reset\+Bus}} (void)
\begin{DoxyCompactList}\small\item\em Resets the I2\+C1 bus. \end{DoxyCompactList}\item 
void \mbox{\hyperlink{i2c1__driver_8c_a826f86a40e425c0280cac832497d48f1}{i2c1\+\_\+driver\+\_\+start}} (void)
\begin{DoxyCompactList}\small\item\em Starts a new I2\+C1 communication. \end{DoxyCompactList}\item 
void \mbox{\hyperlink{i2c1__driver_8c_a9417c263829b30c425f14cd5576b4f44}{i2c1\+\_\+driver\+\_\+restart}} (void)
\begin{DoxyCompactList}\small\item\em Sends a restart condition on I2\+C1 bus. \end{DoxyCompactList}\item 
void \mbox{\hyperlink{i2c1__driver_8c_a822b30de8bc66d6a5dd767066497ad87}{i2c1\+\_\+driver\+\_\+stop}} (void)
\begin{DoxyCompactList}\small\item\em Sends a stop condition on I2\+C1 bus. \end{DoxyCompactList}\item 
bool \mbox{\hyperlink{i2c1__driver_8c_a35f6f9da194842280debb04be644c373}{i2c1\+\_\+driver\+\_\+is\+NACK}} (void)
\begin{DoxyCompactList}\small\item\em Checks if the last I2\+C1 operation was a NACK (Not Acknowledge). \end{DoxyCompactList}\item 
void \mbox{\hyperlink{i2c1__driver_8c_a0c0e213e454c56ad73d3eb1daa66dbec}{i2c1\+\_\+driver\+\_\+start\+RX}} (void)
\begin{DoxyCompactList}\small\item\em Starts receiving data on I2\+C1. \end{DoxyCompactList}\item 
char \mbox{\hyperlink{i2c1__driver_8c_ac99db9ea0d028200180c594b863fb6b0}{i2c1\+\_\+driver\+\_\+get\+RXData}} (void)
\begin{DoxyCompactList}\small\item\em Reads a received byte of data from I2\+C1. \end{DoxyCompactList}\item 
void \mbox{\hyperlink{i2c1__driver_8c_a2a7b6f5a1bb9e19e05a244fc0fbbfac3}{i2c1\+\_\+driver\+\_\+\+TXData}} (uint8\+\_\+t d)
\begin{DoxyCompactList}\small\item\em Transmits a byte of data over I2\+C1. \end{DoxyCompactList}\item 
void \mbox{\hyperlink{i2c1__driver_8c_a7b61d469696ce43586ad65b00fe497c8}{i2c1\+\_\+driver\+\_\+send\+ACK}} (void)
\begin{DoxyCompactList}\small\item\em Sends an ACK (Acknowledge) signal on the I2\+C1 bus. \end{DoxyCompactList}\item 
void \mbox{\hyperlink{i2c1__driver_8c_aee61ef34c048aa4149d15fc7bfba83d0}{i2c1\+\_\+driver\+\_\+send\+NACK}} (void)
\begin{DoxyCompactList}\small\item\em Sends a NACK (Not Acknowledge) signal on the I2\+C1 bus. \end{DoxyCompactList}\item 
void \mbox{\hyperlink{i2c1__driver_8c_af08a3c0de397654999ff28878635b84b}{i2c1\+\_\+driver\+\_\+release\+Clock}} (void)
\begin{DoxyCompactList}\small\item\em Releases the I2\+C1 clock. \end{DoxyCompactList}\item 
bool \mbox{\hyperlink{i2c1__driver_8c_af0a6e32e38bd9467f0ece088996bae76}{i2c1\+\_\+driver\+\_\+is\+Bufer\+Full}} (void)
\begin{DoxyCompactList}\small\item\em Checks if the I2\+C1 buffer is full. \end{DoxyCompactList}\item 
bool \mbox{\hyperlink{i2c1__driver_8c_a5e4122ae176771eaca282cce372486bd}{i2c1\+\_\+driver\+\_\+is\+Start}} (void)
\begin{DoxyCompactList}\small\item\em Checks if the I2\+C1 bus is in the start condition. \end{DoxyCompactList}\item 
bool \mbox{\hyperlink{i2c1__driver_8c_ae7ec5ac5ff5ad12465ca489d1fcf1bee}{i2c1\+\_\+driver\+\_\+is\+Address}} (void)
\begin{DoxyCompactList}\small\item\em Checks if the current I2\+C1 operation is addressing. \end{DoxyCompactList}\item 
bool \mbox{\hyperlink{i2c1__driver_8c_a5b2c47d3881ea90cf7f8654b826176f6}{i2c1\+\_\+driver\+\_\+is\+Stop}} (void)
\begin{DoxyCompactList}\small\item\em Checks if the I2\+C1 bus is in the stop condition. \end{DoxyCompactList}\item 
bool \mbox{\hyperlink{i2c1__driver_8c_a3f7cf8eea1e9a6c4fe27584994f1169e}{i2c1\+\_\+driver\+\_\+is\+Data}} (void)
\begin{DoxyCompactList}\small\item\em Checks if the current I2\+C1 operation is data transfer. \end{DoxyCompactList}\item 
bool \mbox{\hyperlink{i2c1__driver_8c_a678cb4a782b2af3024b46c99302b4f02}{i2c1\+\_\+driver\+\_\+is\+Read}} (void)
\begin{DoxyCompactList}\small\item\em Checks if the current I2\+C1 operation is a read. \end{DoxyCompactList}\item 
void \mbox{\hyperlink{i2c1__driver_8c_a3639e5e0f758d398635ebe19d3e3bfc3}{i2c1\+\_\+driver\+\_\+clear\+Bus\+Collision}} (void)
\begin{DoxyCompactList}\small\item\em Clears the I2\+C1 bus collision flag. \end{DoxyCompactList}\item 
void \mbox{\hyperlink{i2c1__driver_8c_a77c2d72c9fca24dd43990df49d51ca53}{i2c1\+\_\+driver\+\_\+enable\+Start\+IRQ}} (void)
\begin{DoxyCompactList}\small\item\em Enables the I2\+C1 start condition interrupt. \end{DoxyCompactList}\item 
void \mbox{\hyperlink{i2c1__driver_8c_acbc71e0e45d8c7464e36ce128cfd1e9c}{i2c1\+\_\+driver\+\_\+disable\+Start\+IRQ}} (void)
\begin{DoxyCompactList}\small\item\em Disables the I2\+C1 start condition interrupt. \end{DoxyCompactList}\item 
void \mbox{\hyperlink{i2c1__driver_8c_a4a74f266c1ad5e78e30c92ba898f021c}{i2c1\+\_\+driver\+\_\+enable\+Stop\+IRQ}} (void)
\begin{DoxyCompactList}\small\item\em Enables the I2\+C1 stop condition interrupt. \end{DoxyCompactList}\item 
void \mbox{\hyperlink{i2c1__driver_8c_af2ac828c29858571eeb12a8a768b6eaf}{i2c1\+\_\+driver\+\_\+disable\+Stop\+IRQ}} (void)
\begin{DoxyCompactList}\small\item\em Disables the I2\+C1 stop condition interrupt. \end{DoxyCompactList}\item 
void \mbox{\hyperlink{i2c1__driver_8c_aa907711128fc436c2e7542b32148187c}{i2c1\+\_\+driver\+\_\+set\+Bus\+Collision\+ISR}} (\mbox{\hyperlink{i2c1__driver_8h_a397ac9a93480802dfb9e14e4af73e767}{interrupt\+Handler}} handler)
\begin{DoxyCompactList}\small\item\em Sets the interrupt service routine (ISR) for I2\+C1 bus collision. \end{DoxyCompactList}\item 
void \mbox{\hyperlink{i2c1__driver_8c_a406d4d1be058f2358fc613e45db46513}{i2c1\+\_\+driver\+\_\+set\+Master\+I2c\+ISR}} (\mbox{\hyperlink{i2c1__driver_8h_a397ac9a93480802dfb9e14e4af73e767}{interrupt\+Handler}} handler)
\begin{DoxyCompactList}\small\item\em Sets the interrupt service routine (ISR) for I2\+C1 master mode. \end{DoxyCompactList}\item 
void \mbox{\hyperlink{i2c1__driver_8c_aab163b34535ddda4fea4ea0a7cdf5a94}{i2c1\+\_\+driver\+\_\+set\+Slave\+I2c\+ISR}} (\mbox{\hyperlink{i2c1__driver_8h_a397ac9a93480802dfb9e14e4af73e767}{interrupt\+Handler}} handler)
\begin{DoxyCompactList}\small\item\em Sets the interrupt service routine (ISR) for I2\+C1 slave mode. \end{DoxyCompactList}\item 
void \mbox{\hyperlink{i2c1__driver_8c_a226557d5e42f7e29ddaff30606138459}{\+\_\+\+\_\+attribute\+\_\+\+\_\+}} ((interrupt, no\+\_\+auto\+\_\+psv))
\begin{DoxyCompactList}\small\item\em Interrupt service routine for I2\+C1 master interrupt. \end{DoxyCompactList}\end{DoxyCompactItemize}
\doxysubsubsection*{Variables}
\begin{DoxyCompactItemize}
\item 
void(\texorpdfstring{$\ast$}{*} \mbox{\hyperlink{i2c1__driver_8c_ac09931bb2e20ac40b32725e2b92f05d0}{i2c1\+\_\+driver\+\_\+bus\+Collision\+ISR}} )(void)
\item 
void(\texorpdfstring{$\ast$}{*} \mbox{\hyperlink{i2c1__driver_8c_ad8e259907c430d961adee6b26ad06033}{i2c1\+\_\+driver\+\_\+\+Masteri2c\+ISR}} )(void)
\item 
void(\texorpdfstring{$\ast$}{*} \mbox{\hyperlink{i2c1__driver_8c_a9f9b3eb668f0806c719c4d5e8f78089f}{i2c1\+\_\+driver\+\_\+\+Slavei2c\+ISR}} )(void)
\end{DoxyCompactItemize}

\doxysubsection{Detailed Description}
I2C driver source file. 

This file contains definitions of functions decleared in \doxylink{i2c1__driver_8h}{i2c1\+\_\+driver.\+h} 

\doxysubsection{Function Documentation}
\Hypertarget{i2c1__driver_8c_a226557d5e42f7e29ddaff30606138459}\index{i2c1\_driver.c@{i2c1\_driver.c}!\_\_attribute\_\_@{\_\_attribute\_\_}}
\index{\_\_attribute\_\_@{\_\_attribute\_\_}!i2c1\_driver.c@{i2c1\_driver.c}}
\doxysubsubsection{\texorpdfstring{\_\_attribute\_\_()}{\_\_attribute\_\_()}}
{\footnotesize\ttfamily \label{i2c1__driver_8c_a226557d5e42f7e29ddaff30606138459} 
void \+\_\+\+\_\+attribute\+\_\+\+\_\+ (\begin{DoxyParamCaption}\item[{(interrupt, no\+\_\+auto\+\_\+psv)}]{}{}\end{DoxyParamCaption})}

Interrupt service routine for I2\+C1 master interrupt. 

INT1 interrupt handler (button press).

Interrupt service routine for I2\+C1 slave interrupt.

This interrupt handler is called when an I2\+C1 master mode interrupt occurs. It invokes the user-\/defined ISR set by the {\ttfamily i2c1\+\_\+driver\+\_\+set\+Master\+I2c\+ISR} function.

This interrupt handler is called when an I2\+C1 slave mode interrupt occurs. It invokes the user-\/defined ISR set by the {\ttfamily i2c1\+\_\+driver\+\_\+set\+Slave\+I2c\+ISR} function. \Hypertarget{i2c1__driver_8c_a33f284f52c97edb7125db041f382b98e}\index{i2c1\_driver.c@{i2c1\_driver.c}!i2c1\_clearIRQ@{i2c1\_clearIRQ}}
\index{i2c1\_clearIRQ@{i2c1\_clearIRQ}!i2c1\_driver.c@{i2c1\_driver.c}}
\doxysubsubsection{\texorpdfstring{i2c1\_clearIRQ()}{i2c1\_clearIRQ()}}
{\footnotesize\ttfamily \label{i2c1__driver_8c_a33f284f52c97edb7125db041f382b98e} 
void i2c1\+\_\+clear\+IRQ (\begin{DoxyParamCaption}\item[{void}]{}{}\end{DoxyParamCaption})}

Clears the I2\+C1 interrupt flags. 

Resets the master and slave interrupt flags to 0. \Hypertarget{i2c1__driver_8c_ad88ed6deb0c925a79b507f0eced17c38}\index{i2c1\_driver.c@{i2c1\_driver.c}!i2c1\_disableIRQ@{i2c1\_disableIRQ}}
\index{i2c1\_disableIRQ@{i2c1\_disableIRQ}!i2c1\_driver.c@{i2c1\_driver.c}}
\doxysubsubsection{\texorpdfstring{i2c1\_disableIRQ()}{i2c1\_disableIRQ()}}
{\footnotesize\ttfamily \label{i2c1__driver_8c_ad88ed6deb0c925a79b507f0eced17c38} 
void i2c1\+\_\+disable\+IRQ (\begin{DoxyParamCaption}\item[{void}]{}{}\end{DoxyParamCaption})}

Disables the I2\+C1 master and slave interrupt sources. 

Clears the interrupt enable bits for both master and slave I2\+C1 events. \Hypertarget{i2c1__driver_8c_a3639e5e0f758d398635ebe19d3e3bfc3}\index{i2c1\_driver.c@{i2c1\_driver.c}!i2c1\_driver\_clearBusCollision@{i2c1\_driver\_clearBusCollision}}
\index{i2c1\_driver\_clearBusCollision@{i2c1\_driver\_clearBusCollision}!i2c1\_driver.c@{i2c1\_driver.c}}
\doxysubsubsection{\texorpdfstring{i2c1\_driver\_clearBusCollision()}{i2c1\_driver\_clearBusCollision()}}
{\footnotesize\ttfamily \label{i2c1__driver_8c_a3639e5e0f758d398635ebe19d3e3bfc3} 
void i2c1\+\_\+driver\+\_\+clear\+Bus\+Collision (\begin{DoxyParamCaption}\item[{void}]{}{}\end{DoxyParamCaption})}

Clears the I2\+C1 bus collision flag. 

This function clears the Bus Collision (BCL) flag in the I2\+C1\+STAT register. This is necessary after handling a bus collision event to reset the flag. \Hypertarget{i2c1__driver_8c_aff5fb84305b4e5655721c950a3488196}\index{i2c1\_driver.c@{i2c1\_driver.c}!i2c1\_driver\_close@{i2c1\_driver\_close}}
\index{i2c1\_driver\_close@{i2c1\_driver\_close}!i2c1\_driver.c@{i2c1\_driver.c}}
\doxysubsubsection{\texorpdfstring{i2c1\_driver\_close()}{i2c1\_driver\_close()}}
{\footnotesize\ttfamily \label{i2c1__driver_8c_aff5fb84305b4e5655721c950a3488196} 
void i2c1\+\_\+driver\+\_\+close (\begin{DoxyParamCaption}\item[{void}]{}{}\end{DoxyParamCaption})}

Disables the I2\+C1 peripheral by clearing the enable bit. 

This function turns off the I2\+C1 hardware module. \Hypertarget{i2c1__driver_8c_acbc71e0e45d8c7464e36ce128cfd1e9c}\index{i2c1\_driver.c@{i2c1\_driver.c}!i2c1\_driver\_disableStartIRQ@{i2c1\_driver\_disableStartIRQ}}
\index{i2c1\_driver\_disableStartIRQ@{i2c1\_driver\_disableStartIRQ}!i2c1\_driver.c@{i2c1\_driver.c}}
\doxysubsubsection{\texorpdfstring{i2c1\_driver\_disableStartIRQ()}{i2c1\_driver\_disableStartIRQ()}}
{\footnotesize\ttfamily \label{i2c1__driver_8c_acbc71e0e45d8c7464e36ce128cfd1e9c} 
void i2c1\+\_\+driver\+\_\+disable\+Start\+IRQ (\begin{DoxyParamCaption}\item[{void}]{}{}\end{DoxyParamCaption})}

Disables the I2\+C1 start condition interrupt. 

This function disables the interrupt for the start condition detected on the I2\+C1 bus by clearing the SCIE bit in the I2\+C1\+CONH register. This prevents the I2C controller from generating interrupts on the start condition. \Hypertarget{i2c1__driver_8c_af2ac828c29858571eeb12a8a768b6eaf}\index{i2c1\_driver.c@{i2c1\_driver.c}!i2c1\_driver\_disableStopIRQ@{i2c1\_driver\_disableStopIRQ}}
\index{i2c1\_driver\_disableStopIRQ@{i2c1\_driver\_disableStopIRQ}!i2c1\_driver.c@{i2c1\_driver.c}}
\doxysubsubsection{\texorpdfstring{i2c1\_driver\_disableStopIRQ()}{i2c1\_driver\_disableStopIRQ()}}
{\footnotesize\ttfamily \label{i2c1__driver_8c_af2ac828c29858571eeb12a8a768b6eaf} 
void i2c1\+\_\+driver\+\_\+disable\+Stop\+IRQ (\begin{DoxyParamCaption}\item[{void}]{}{}\end{DoxyParamCaption})}

Disables the I2\+C1 stop condition interrupt. 

This function disables the interrupt for the stop condition detected on the I2\+C1 bus by clearing the PCIE bit in the I2\+C1\+CONH register. This prevents the I2C controller from generating interrupts on the stop condition. \Hypertarget{i2c1__driver_8c_a73e12d1ac2f9ed036a413a4ec4973512}\index{i2c1\_driver.c@{i2c1\_driver.c}!i2c1\_driver\_driver\_open@{i2c1\_driver\_driver\_open}}
\index{i2c1\_driver\_driver\_open@{i2c1\_driver\_driver\_open}!i2c1\_driver.c@{i2c1\_driver.c}}
\doxysubsubsection{\texorpdfstring{i2c1\_driver\_driver\_open()}{i2c1\_driver\_driver\_open()}}
{\footnotesize\ttfamily \label{i2c1__driver_8c_a73e12d1ac2f9ed036a413a4ec4973512} 
bool i2c1\+\_\+driver\+\_\+driver\+\_\+open (\begin{DoxyParamCaption}\item[{void}]{}{}\end{DoxyParamCaption})}

Opens the I2\+C1 driver and initializes the hardware. 

This function checks if the I2\+C1 module is disabled and, if so, initializes the hardware by configuring control and status registers, setting the baud rate, and enabling the module.

\begin{DoxyReturn}{Returns}
true if the I2\+C1 module was successfully initialized, false if it is already enabled. 
\end{DoxyReturn}
\Hypertarget{i2c1__driver_8c_a77c2d72c9fca24dd43990df49d51ca53}\index{i2c1\_driver.c@{i2c1\_driver.c}!i2c1\_driver\_enableStartIRQ@{i2c1\_driver\_enableStartIRQ}}
\index{i2c1\_driver\_enableStartIRQ@{i2c1\_driver\_enableStartIRQ}!i2c1\_driver.c@{i2c1\_driver.c}}
\doxysubsubsection{\texorpdfstring{i2c1\_driver\_enableStartIRQ()}{i2c1\_driver\_enableStartIRQ()}}
{\footnotesize\ttfamily \label{i2c1__driver_8c_a77c2d72c9fca24dd43990df49d51ca53} 
void i2c1\+\_\+driver\+\_\+enable\+Start\+IRQ (\begin{DoxyParamCaption}\item[{void}]{}{}\end{DoxyParamCaption})}

Enables the I2\+C1 start condition interrupt. 

This function enables the interrupt for the start condition detected on the I2\+C1 bus by setting the SCIE bit in the I2\+C1\+CONH register. When this interrupt is enabled, the I2C controller will generate an interrupt on the start condition. \Hypertarget{i2c1__driver_8c_a4a74f266c1ad5e78e30c92ba898f021c}\index{i2c1\_driver.c@{i2c1\_driver.c}!i2c1\_driver\_enableStopIRQ@{i2c1\_driver\_enableStopIRQ}}
\index{i2c1\_driver\_enableStopIRQ@{i2c1\_driver\_enableStopIRQ}!i2c1\_driver.c@{i2c1\_driver.c}}
\doxysubsubsection{\texorpdfstring{i2c1\_driver\_enableStopIRQ()}{i2c1\_driver\_enableStopIRQ()}}
{\footnotesize\ttfamily \label{i2c1__driver_8c_a4a74f266c1ad5e78e30c92ba898f021c} 
void i2c1\+\_\+driver\+\_\+enable\+Stop\+IRQ (\begin{DoxyParamCaption}\item[{void}]{}{}\end{DoxyParamCaption})}

Enables the I2\+C1 stop condition interrupt. 

This function enables the interrupt for the stop condition detected on the I2\+C1 bus by setting the PCIE bit in the I2\+C1\+CONH register. When this interrupt is enabled, the I2C controller will generate an interrupt on the stop condition. \Hypertarget{i2c1__driver_8c_ac99db9ea0d028200180c594b863fb6b0}\index{i2c1\_driver.c@{i2c1\_driver.c}!i2c1\_driver\_getRXData@{i2c1\_driver\_getRXData}}
\index{i2c1\_driver\_getRXData@{i2c1\_driver\_getRXData}!i2c1\_driver.c@{i2c1\_driver.c}}
\doxysubsubsection{\texorpdfstring{i2c1\_driver\_getRXData()}{i2c1\_driver\_getRXData()}}
{\footnotesize\ttfamily \label{i2c1__driver_8c_ac99db9ea0d028200180c594b863fb6b0} 
char i2c1\+\_\+driver\+\_\+get\+RXData (\begin{DoxyParamCaption}\item[{void}]{}{}\end{DoxyParamCaption})}

Reads a received byte of data from I2\+C1. 

This function retrieves the received data from the I2\+C1\+RCV register after enabling the RX mode.

\begin{DoxyReturn}{Returns}
The byte of data received on the I2\+C1 bus. 
\end{DoxyReturn}
\Hypertarget{i2c1__driver_8c_a0f9e55c5736c1b1fc31d3055093bf997}\index{i2c1\_driver.c@{i2c1\_driver.c}!i2c1\_driver\_initSlaveHardware@{i2c1\_driver\_initSlaveHardware}}
\index{i2c1\_driver\_initSlaveHardware@{i2c1\_driver\_initSlaveHardware}!i2c1\_driver.c@{i2c1\_driver.c}}
\doxysubsubsection{\texorpdfstring{i2c1\_driver\_initSlaveHardware()}{i2c1\_driver\_initSlaveHardware()}}
{\footnotesize\ttfamily \label{i2c1__driver_8c_a0f9e55c5736c1b1fc31d3055093bf997} 
bool i2c1\+\_\+driver\+\_\+init\+Slave\+Hardware (\begin{DoxyParamCaption}\item[{void}]{}{}\end{DoxyParamCaption})}

Initializes the I2\+C1 hardware in slave mode. 

This function configures the I2\+C1 module for slave operation by enabling the address and data hold features and setting the strength of the slave pull-\/ups. The module is then enabled.

\begin{DoxyReturn}{Returns}
true if the I2\+C1 module was successfully initialized in slave mode, false if the module is already enabled. 
\end{DoxyReturn}
\Hypertarget{i2c1__driver_8c_ae7ec5ac5ff5ad12465ca489d1fcf1bee}\index{i2c1\_driver.c@{i2c1\_driver.c}!i2c1\_driver\_isAddress@{i2c1\_driver\_isAddress}}
\index{i2c1\_driver\_isAddress@{i2c1\_driver\_isAddress}!i2c1\_driver.c@{i2c1\_driver.c}}
\doxysubsubsection{\texorpdfstring{i2c1\_driver\_isAddress()}{i2c1\_driver\_isAddress()}}
{\footnotesize\ttfamily \label{i2c1__driver_8c_ae7ec5ac5ff5ad12465ca489d1fcf1bee} 
bool i2c1\+\_\+driver\+\_\+is\+Address (\begin{DoxyParamCaption}\item[{void}]{}{}\end{DoxyParamCaption})}

Checks if the current I2\+C1 operation is addressing. 

This function checks the value of the D\+\_\+A bit in the I2\+C1\+STAT register. If D\+\_\+A is 0, it indicates that the current I2C operation is addressing, meaning that the master is addressing the slave device.

\begin{DoxyReturn}{Returns}
true if the current operation is addressing, false otherwise. 
\end{DoxyReturn}
\Hypertarget{i2c1__driver_8c_af0a6e32e38bd9467f0ece088996bae76}\index{i2c1\_driver.c@{i2c1\_driver.c}!i2c1\_driver\_isBuferFull@{i2c1\_driver\_isBuferFull}}
\index{i2c1\_driver\_isBuferFull@{i2c1\_driver\_isBuferFull}!i2c1\_driver.c@{i2c1\_driver.c}}
\doxysubsubsection{\texorpdfstring{i2c1\_driver\_isBuferFull()}{i2c1\_driver\_isBuferFull()}}
{\footnotesize\ttfamily \label{i2c1__driver_8c_af0a6e32e38bd9467f0ece088996bae76} 
bool i2c1\+\_\+driver\+\_\+is\+Bufer\+Full (\begin{DoxyParamCaption}\item[{void}]{}{}\end{DoxyParamCaption})}

Checks if the I2\+C1 buffer is full. 

This function checks if either the receive buffer (RBF) or transmit buffer (TBF) in the I2\+C1\+STAT register is full, indicating that data is ready to be read or written.

\begin{DoxyReturn}{Returns}
true if the buffer is full, false otherwise. 
\end{DoxyReturn}
\Hypertarget{i2c1__driver_8c_a3f7cf8eea1e9a6c4fe27584994f1169e}\index{i2c1\_driver.c@{i2c1\_driver.c}!i2c1\_driver\_isData@{i2c1\_driver\_isData}}
\index{i2c1\_driver\_isData@{i2c1\_driver\_isData}!i2c1\_driver.c@{i2c1\_driver.c}}
\doxysubsubsection{\texorpdfstring{i2c1\_driver\_isData()}{i2c1\_driver\_isData()}}
{\footnotesize\ttfamily \label{i2c1__driver_8c_a3f7cf8eea1e9a6c4fe27584994f1169e} 
bool i2c1\+\_\+driver\+\_\+is\+Data (\begin{DoxyParamCaption}\item[{void}]{}{}\end{DoxyParamCaption})}

Checks if the current I2\+C1 operation is data transfer. 

This function checks the value of the D\+\_\+A bit in the I2\+C1\+STAT register. If D\+\_\+A is 1, it indicates that the current operation is data transfer, meaning that the I2C bus is currently transferring data (not addressing).

\begin{DoxyReturn}{Returns}
true if the current operation is data transfer, false otherwise. 
\end{DoxyReturn}
\Hypertarget{i2c1__driver_8c_a35f6f9da194842280debb04be644c373}\index{i2c1\_driver.c@{i2c1\_driver.c}!i2c1\_driver\_isNACK@{i2c1\_driver\_isNACK}}
\index{i2c1\_driver\_isNACK@{i2c1\_driver\_isNACK}!i2c1\_driver.c@{i2c1\_driver.c}}
\doxysubsubsection{\texorpdfstring{i2c1\_driver\_isNACK()}{i2c1\_driver\_isNACK()}}
{\footnotesize\ttfamily \label{i2c1__driver_8c_a35f6f9da194842280debb04be644c373} 
bool i2c1\+\_\+driver\+\_\+is\+NACK (\begin{DoxyParamCaption}\item[{void}]{}{}\end{DoxyParamCaption})}

Checks if the last I2\+C1 operation was a NACK (Not Acknowledge). 

This function checks the ACKSTAT bit in the I2\+C1\+STAT register to determine whether the last transmission was acknowledged by the slave.

\begin{DoxyReturn}{Returns}
true if a NACK was received, false otherwise. 
\end{DoxyReturn}
\Hypertarget{i2c1__driver_8c_a678cb4a782b2af3024b46c99302b4f02}\index{i2c1\_driver.c@{i2c1\_driver.c}!i2c1\_driver\_isRead@{i2c1\_driver\_isRead}}
\index{i2c1\_driver\_isRead@{i2c1\_driver\_isRead}!i2c1\_driver.c@{i2c1\_driver.c}}
\doxysubsubsection{\texorpdfstring{i2c1\_driver\_isRead()}{i2c1\_driver\_isRead()}}
{\footnotesize\ttfamily \label{i2c1__driver_8c_a678cb4a782b2af3024b46c99302b4f02} 
bool i2c1\+\_\+driver\+\_\+is\+Read (\begin{DoxyParamCaption}\item[{void}]{}{}\end{DoxyParamCaption})}

Checks if the current I2\+C1 operation is a read. 

This function checks the value of the R\+\_\+W bit in the I2\+C1\+STAT register. If R\+\_\+W is 1, it indicates that the current operation is a read operation, meaning that the master is reading data from the slave device.

\begin{DoxyReturn}{Returns}
true if the current operation is a read, false if it is a write. 
\end{DoxyReturn}
\Hypertarget{i2c1__driver_8c_a5e4122ae176771eaca282cce372486bd}\index{i2c1\_driver.c@{i2c1\_driver.c}!i2c1\_driver\_isStart@{i2c1\_driver\_isStart}}
\index{i2c1\_driver\_isStart@{i2c1\_driver\_isStart}!i2c1\_driver.c@{i2c1\_driver.c}}
\doxysubsubsection{\texorpdfstring{i2c1\_driver\_isStart()}{i2c1\_driver\_isStart()}}
{\footnotesize\ttfamily \label{i2c1__driver_8c_a5e4122ae176771eaca282cce372486bd} 
bool i2c1\+\_\+driver\+\_\+is\+Start (\begin{DoxyParamCaption}\item[{void}]{}{}\end{DoxyParamCaption})}

Checks if the I2\+C1 bus is in the start condition. 

This function checks the value of the S bit in the I2\+C1\+STAT register to determine if the I2C bus is currently in the start condition (S). This bit is set when a start condition is detected on the bus.

\begin{DoxyReturn}{Returns}
true if the bus is in the start condition, false otherwise. 
\end{DoxyReturn}
\Hypertarget{i2c1__driver_8c_a5b2c47d3881ea90cf7f8654b826176f6}\index{i2c1\_driver.c@{i2c1\_driver.c}!i2c1\_driver\_isStop@{i2c1\_driver\_isStop}}
\index{i2c1\_driver\_isStop@{i2c1\_driver\_isStop}!i2c1\_driver.c@{i2c1\_driver.c}}
\doxysubsubsection{\texorpdfstring{i2c1\_driver\_isStop()}{i2c1\_driver\_isStop()}}
{\footnotesize\ttfamily \label{i2c1__driver_8c_a5b2c47d3881ea90cf7f8654b826176f6} 
bool i2c1\+\_\+driver\+\_\+is\+Stop (\begin{DoxyParamCaption}\item[{void}]{}{}\end{DoxyParamCaption})}

Checks if the I2\+C1 bus is in the stop condition. 

This function checks the value of the P bit in the I2\+C1\+STAT register to determine if the bus is currently in the stop condition (P), which indicates the end of a communication.

\begin{DoxyReturn}{Returns}
true if the bus is in the stop condition, false otherwise. 
\end{DoxyReturn}
\Hypertarget{i2c1__driver_8c_af08a3c0de397654999ff28878635b84b}\index{i2c1\_driver.c@{i2c1\_driver.c}!i2c1\_driver\_releaseClock@{i2c1\_driver\_releaseClock}}
\index{i2c1\_driver\_releaseClock@{i2c1\_driver\_releaseClock}!i2c1\_driver.c@{i2c1\_driver.c}}
\doxysubsubsection{\texorpdfstring{i2c1\_driver\_releaseClock()}{i2c1\_driver\_releaseClock()}}
{\footnotesize\ttfamily \label{i2c1__driver_8c_af08a3c0de397654999ff28878635b84b} 
void i2c1\+\_\+driver\+\_\+release\+Clock (\begin{DoxyParamCaption}\item[{void}]{}{}\end{DoxyParamCaption})}

Releases the I2\+C1 clock. 

This function sets the SCLREL bit in the I2\+C1\+CONL register to release the I2\+C1 clock. It is used to free the clock if it has been held by the I2C controller. \Hypertarget{i2c1__driver_8c_a3291584a36361a8b886a5565a0897474}\index{i2c1\_driver.c@{i2c1\_driver.c}!i2c1\_driver\_resetBus@{i2c1\_driver\_resetBus}}
\index{i2c1\_driver\_resetBus@{i2c1\_driver\_resetBus}!i2c1\_driver.c@{i2c1\_driver.c}}
\doxysubsubsection{\texorpdfstring{i2c1\_driver\_resetBus()}{i2c1\_driver\_resetBus()}}
{\footnotesize\ttfamily \label{i2c1__driver_8c_a3291584a36361a8b886a5565a0897474} 
void i2c1\+\_\+driver\+\_\+reset\+Bus (\begin{DoxyParamCaption}\item[{void}]{}{}\end{DoxyParamCaption})}

Resets the I2\+C1 bus. 

This function is intended to reset the I2C bus, but it is currently not implemented. \Hypertarget{i2c1__driver_8c_a9417c263829b30c425f14cd5576b4f44}\index{i2c1\_driver.c@{i2c1\_driver.c}!i2c1\_driver\_restart@{i2c1\_driver\_restart}}
\index{i2c1\_driver\_restart@{i2c1\_driver\_restart}!i2c1\_driver.c@{i2c1\_driver.c}}
\doxysubsubsection{\texorpdfstring{i2c1\_driver\_restart()}{i2c1\_driver\_restart()}}
{\footnotesize\ttfamily \label{i2c1__driver_8c_a9417c263829b30c425f14cd5576b4f44} 
void i2c1\+\_\+driver\+\_\+restart (\begin{DoxyParamCaption}\item[{void}]{}{}\end{DoxyParamCaption})}

Sends a restart condition on I2\+C1 bus. 

This function generates a restart condition (RSEN) to resume communication with the slave device without releasing the bus. \Hypertarget{i2c1__driver_8c_a7b61d469696ce43586ad65b00fe497c8}\index{i2c1\_driver.c@{i2c1\_driver.c}!i2c1\_driver\_sendACK@{i2c1\_driver\_sendACK}}
\index{i2c1\_driver\_sendACK@{i2c1\_driver\_sendACK}!i2c1\_driver.c@{i2c1\_driver.c}}
\doxysubsubsection{\texorpdfstring{i2c1\_driver\_sendACK()}{i2c1\_driver\_sendACK()}}
{\footnotesize\ttfamily \label{i2c1__driver_8c_a7b61d469696ce43586ad65b00fe497c8} 
void i2c1\+\_\+driver\+\_\+send\+ACK (\begin{DoxyParamCaption}\item[{void}]{}{}\end{DoxyParamCaption})}

Sends an ACK (Acknowledge) signal on the I2\+C1 bus. 

This function sets the ACKDT bit to 0 and enables the ACKEN bit to initiate the transmission of an ACK signal to the slave device. \Hypertarget{i2c1__driver_8c_aee61ef34c048aa4149d15fc7bfba83d0}\index{i2c1\_driver.c@{i2c1\_driver.c}!i2c1\_driver\_sendNACK@{i2c1\_driver\_sendNACK}}
\index{i2c1\_driver\_sendNACK@{i2c1\_driver\_sendNACK}!i2c1\_driver.c@{i2c1\_driver.c}}
\doxysubsubsection{\texorpdfstring{i2c1\_driver\_sendNACK()}{i2c1\_driver\_sendNACK()}}
{\footnotesize\ttfamily \label{i2c1__driver_8c_aee61ef34c048aa4149d15fc7bfba83d0} 
void i2c1\+\_\+driver\+\_\+send\+NACK (\begin{DoxyParamCaption}\item[{void}]{}{}\end{DoxyParamCaption})}

Sends a NACK (Not Acknowledge) signal on the I2\+C1 bus. 

This function sets the ACKDT bit to 1 and enables the ACKEN bit to initiate the transmission of a NACK signal to the slave device. \Hypertarget{i2c1__driver_8c_aa907711128fc436c2e7542b32148187c}\index{i2c1\_driver.c@{i2c1\_driver.c}!i2c1\_driver\_setBusCollisionISR@{i2c1\_driver\_setBusCollisionISR}}
\index{i2c1\_driver\_setBusCollisionISR@{i2c1\_driver\_setBusCollisionISR}!i2c1\_driver.c@{i2c1\_driver.c}}
\doxysubsubsection{\texorpdfstring{i2c1\_driver\_setBusCollisionISR()}{i2c1\_driver\_setBusCollisionISR()}}
{\footnotesize\ttfamily \label{i2c1__driver_8c_aa907711128fc436c2e7542b32148187c} 
void i2c1\+\_\+driver\+\_\+set\+Bus\+Collision\+ISR (\begin{DoxyParamCaption}\item[{\mbox{\hyperlink{i2c1__driver_8h_a397ac9a93480802dfb9e14e4af73e767}{interrupt\+Handler}}}]{handler}{}\end{DoxyParamCaption})}

Sets the interrupt service routine (ISR) for I2\+C1 bus collision. 

This function allows the user to set a custom interrupt handler for bus collision events on the I2\+C1 bus. The handler is called when a bus collision occurs.

\begin{DoxyParams}{Parameters}
{\em handler} & The interrupt handler function to be set for the bus collision ISR. \\
\hline
\end{DoxyParams}
\Hypertarget{i2c1__driver_8c_a406d4d1be058f2358fc613e45db46513}\index{i2c1\_driver.c@{i2c1\_driver.c}!i2c1\_driver\_setMasterI2cISR@{i2c1\_driver\_setMasterI2cISR}}
\index{i2c1\_driver\_setMasterI2cISR@{i2c1\_driver\_setMasterI2cISR}!i2c1\_driver.c@{i2c1\_driver.c}}
\doxysubsubsection{\texorpdfstring{i2c1\_driver\_setMasterI2cISR()}{i2c1\_driver\_setMasterI2cISR()}}
{\footnotesize\ttfamily \label{i2c1__driver_8c_a406d4d1be058f2358fc613e45db46513} 
void i2c1\+\_\+driver\+\_\+set\+Master\+I2c\+ISR (\begin{DoxyParamCaption}\item[{\mbox{\hyperlink{i2c1__driver_8h_a397ac9a93480802dfb9e14e4af73e767}{interrupt\+Handler}}}]{handler}{}\end{DoxyParamCaption})}

Sets the interrupt service routine (ISR) for I2\+C1 master mode. 

This function allows the user to set a custom interrupt handler for master mode events on the I2\+C1 bus. The handler is called when the I2\+C1 controller is in master mode and the interrupt is triggered.

\begin{DoxyParams}{Parameters}
{\em handler} & The interrupt handler function to be set for the master mode ISR. \\
\hline
\end{DoxyParams}
\Hypertarget{i2c1__driver_8c_aab163b34535ddda4fea4ea0a7cdf5a94}\index{i2c1\_driver.c@{i2c1\_driver.c}!i2c1\_driver\_setSlaveI2cISR@{i2c1\_driver\_setSlaveI2cISR}}
\index{i2c1\_driver\_setSlaveI2cISR@{i2c1\_driver\_setSlaveI2cISR}!i2c1\_driver.c@{i2c1\_driver.c}}
\doxysubsubsection{\texorpdfstring{i2c1\_driver\_setSlaveI2cISR()}{i2c1\_driver\_setSlaveI2cISR()}}
{\footnotesize\ttfamily \label{i2c1__driver_8c_aab163b34535ddda4fea4ea0a7cdf5a94} 
void i2c1\+\_\+driver\+\_\+set\+Slave\+I2c\+ISR (\begin{DoxyParamCaption}\item[{\mbox{\hyperlink{i2c1__driver_8h_a397ac9a93480802dfb9e14e4af73e767}{interrupt\+Handler}}}]{handler}{}\end{DoxyParamCaption})}

Sets the interrupt service routine (ISR) for I2\+C1 slave mode. 

This function allows the user to set a custom interrupt handler for slave mode events on the I2\+C1 bus. The handler is called when the I2\+C1 controller is in slave mode and the interrupt is triggered.

\begin{DoxyParams}{Parameters}
{\em handler} & The interrupt handler function to be set for the slave mode ISR. \\
\hline
\end{DoxyParams}
\Hypertarget{i2c1__driver_8c_a826f86a40e425c0280cac832497d48f1}\index{i2c1\_driver.c@{i2c1\_driver.c}!i2c1\_driver\_start@{i2c1\_driver\_start}}
\index{i2c1\_driver\_start@{i2c1\_driver\_start}!i2c1\_driver.c@{i2c1\_driver.c}}
\doxysubsubsection{\texorpdfstring{i2c1\_driver\_start()}{i2c1\_driver\_start()}}
{\footnotesize\ttfamily \label{i2c1__driver_8c_a826f86a40e425c0280cac832497d48f1} 
void i2c1\+\_\+driver\+\_\+start (\begin{DoxyParamCaption}\item[{void}]{}{}\end{DoxyParamCaption})}

Starts a new I2\+C1 communication. 

This function generates a start condition (SEN) to initiate communication with the slave device. \Hypertarget{i2c1__driver_8c_a0c0e213e454c56ad73d3eb1daa66dbec}\index{i2c1\_driver.c@{i2c1\_driver.c}!i2c1\_driver\_startRX@{i2c1\_driver\_startRX}}
\index{i2c1\_driver\_startRX@{i2c1\_driver\_startRX}!i2c1\_driver.c@{i2c1\_driver.c}}
\doxysubsubsection{\texorpdfstring{i2c1\_driver\_startRX()}{i2c1\_driver\_startRX()}}
{\footnotesize\ttfamily \label{i2c1__driver_8c_a0c0e213e454c56ad73d3eb1daa66dbec} 
void i2c1\+\_\+driver\+\_\+start\+RX (\begin{DoxyParamCaption}\item[{void}]{}{}\end{DoxyParamCaption})}

Starts receiving data on I2\+C1. 

This function enables the receive mode (RCEN) to allow the I2\+C1 module to receive data from the master device. \Hypertarget{i2c1__driver_8c_a822b30de8bc66d6a5dd767066497ad87}\index{i2c1\_driver.c@{i2c1\_driver.c}!i2c1\_driver\_stop@{i2c1\_driver\_stop}}
\index{i2c1\_driver\_stop@{i2c1\_driver\_stop}!i2c1\_driver.c@{i2c1\_driver.c}}
\doxysubsubsection{\texorpdfstring{i2c1\_driver\_stop()}{i2c1\_driver\_stop()}}
{\footnotesize\ttfamily \label{i2c1__driver_8c_a822b30de8bc66d6a5dd767066497ad87} 
void i2c1\+\_\+driver\+\_\+stop (\begin{DoxyParamCaption}\item[{void}]{}{}\end{DoxyParamCaption})}

Sends a stop condition on I2\+C1 bus. 

This function generates a stop condition (PEN) to end communication with the slave device and release the bus. \Hypertarget{i2c1__driver_8c_a2a7b6f5a1bb9e19e05a244fc0fbbfac3}\index{i2c1\_driver.c@{i2c1\_driver.c}!i2c1\_driver\_TXData@{i2c1\_driver\_TXData}}
\index{i2c1\_driver\_TXData@{i2c1\_driver\_TXData}!i2c1\_driver.c@{i2c1\_driver.c}}
\doxysubsubsection{\texorpdfstring{i2c1\_driver\_TXData()}{i2c1\_driver\_TXData()}}
{\footnotesize\ttfamily \label{i2c1__driver_8c_a2a7b6f5a1bb9e19e05a244fc0fbbfac3} 
void i2c1\+\_\+driver\+\_\+\+TXData (\begin{DoxyParamCaption}\item[{uint8\+\_\+t}]{d}{}\end{DoxyParamCaption})}

Transmits a byte of data over I2\+C1. 

This function sends the specified byte of data over the I2\+C1 bus by writing it to the I2\+C1\+TRN register.

\begin{DoxyParams}{Parameters}
{\em d} & The byte of data to be transmitted. \\
\hline
\end{DoxyParams}
\Hypertarget{i2c1__driver_8c_a8ef15a19099711e8ee10fd31a7d7b847}\index{i2c1\_driver.c@{i2c1\_driver.c}!i2c1\_enableIRQ@{i2c1\_enableIRQ}}
\index{i2c1\_enableIRQ@{i2c1\_enableIRQ}!i2c1\_driver.c@{i2c1\_driver.c}}
\doxysubsubsection{\texorpdfstring{i2c1\_enableIRQ()}{i2c1\_enableIRQ()}}
{\footnotesize\ttfamily \label{i2c1__driver_8c_a8ef15a19099711e8ee10fd31a7d7b847} 
void i2c1\+\_\+enable\+IRQ (\begin{DoxyParamCaption}\item[{void}]{}{}\end{DoxyParamCaption})}

Enables the I2\+C1 master and slave interrupt sources. 

Sets the interrupt enable bits for both master and slave I2\+C1 events. \Hypertarget{i2c1__driver_8c_a3a562d793c89fe5f86c8954605041f1f}\index{i2c1\_driver.c@{i2c1\_driver.c}!i2c1\_IRQisEnabled@{i2c1\_IRQisEnabled}}
\index{i2c1\_IRQisEnabled@{i2c1\_IRQisEnabled}!i2c1\_driver.c@{i2c1\_driver.c}}
\doxysubsubsection{\texorpdfstring{i2c1\_IRQisEnabled()}{i2c1\_IRQisEnabled()}}
{\footnotesize\ttfamily \label{i2c1__driver_8c_a3a562d793c89fe5f86c8954605041f1f} 
bool i2c1\+\_\+\+IRQis\+Enabled (\begin{DoxyParamCaption}\item[{void}]{}{}\end{DoxyParamCaption})}

Checks whether I2\+C1 interrupts are currently enabled. 

\begin{DoxyReturn}{Returns}
true if either master or slave interrupt is enabled; false otherwise. 
\end{DoxyReturn}
\Hypertarget{i2c1__driver_8c_a733a1bea54d71551298a6780208796c9}\index{i2c1\_driver.c@{i2c1\_driver.c}!i2c1\_setIRQ@{i2c1\_setIRQ}}
\index{i2c1\_setIRQ@{i2c1\_setIRQ}!i2c1\_driver.c@{i2c1\_driver.c}}
\doxysubsubsection{\texorpdfstring{i2c1\_setIRQ()}{i2c1\_setIRQ()}}
{\footnotesize\ttfamily \label{i2c1__driver_8c_a733a1bea54d71551298a6780208796c9} 
void i2c1\+\_\+set\+IRQ (\begin{DoxyParamCaption}\item[{void}]{}{}\end{DoxyParamCaption})}

Sets the I2\+C1 interrupt flags. 

Forces both the master and slave interrupt flags to 1. \Hypertarget{i2c1__driver_8c_abac55eee70c770587d584181a98e1f96}\index{i2c1\_driver.c@{i2c1\_driver.c}!i2c1\_waitForEvent@{i2c1\_waitForEvent}}
\index{i2c1\_waitForEvent@{i2c1\_waitForEvent}!i2c1\_driver.c@{i2c1\_driver.c}}
\doxysubsubsection{\texorpdfstring{i2c1\_waitForEvent()}{i2c1\_waitForEvent()}}
{\footnotesize\ttfamily \label{i2c1__driver_8c_abac55eee70c770587d584181a98e1f96} 
void i2c1\+\_\+wait\+For\+Event (\begin{DoxyParamCaption}\item[{uint16\+\_\+t \texorpdfstring{$\ast$}{*}}]{timeout}{}\end{DoxyParamCaption})}

Waits for an I2\+C1 interrupt event with an optional timeout. 

This function waits in a loop until either the master or slave interrupt flag is set. If both are clear initially, it continuously polls for a change.

\begin{DoxyParams}{Parameters}
{\em timeout} & Pointer to a user-\/defined timeout value (currently unused). \\
\hline
\end{DoxyParams}

\doxysubsection{Variable Documentation}
\Hypertarget{i2c1__driver_8c_ac09931bb2e20ac40b32725e2b92f05d0}\index{i2c1\_driver.c@{i2c1\_driver.c}!i2c1\_driver\_busCollisionISR@{i2c1\_driver\_busCollisionISR}}
\index{i2c1\_driver\_busCollisionISR@{i2c1\_driver\_busCollisionISR}!i2c1\_driver.c@{i2c1\_driver.c}}
\doxysubsubsection{\texorpdfstring{i2c1\_driver\_busCollisionISR}{i2c1\_driver\_busCollisionISR}}
{\footnotesize\ttfamily \label{i2c1__driver_8c_ac09931bb2e20ac40b32725e2b92f05d0} 
void(\texorpdfstring{$\ast$}{*} i2c1\+\_\+driver\+\_\+bus\+Collision\+ISR) (void) (\begin{DoxyParamCaption}\item[{void}]{}{}\end{DoxyParamCaption})}

\Hypertarget{i2c1__driver_8c_ad8e259907c430d961adee6b26ad06033}\index{i2c1\_driver.c@{i2c1\_driver.c}!i2c1\_driver\_Masteri2cISR@{i2c1\_driver\_Masteri2cISR}}
\index{i2c1\_driver\_Masteri2cISR@{i2c1\_driver\_Masteri2cISR}!i2c1\_driver.c@{i2c1\_driver.c}}
\doxysubsubsection{\texorpdfstring{i2c1\_driver\_Masteri2cISR}{i2c1\_driver\_Masteri2cISR}}
{\footnotesize\ttfamily \label{i2c1__driver_8c_ad8e259907c430d961adee6b26ad06033} 
void(\texorpdfstring{$\ast$}{*} i2c1\+\_\+driver\+\_\+\+Masteri2c\+ISR) (void) (\begin{DoxyParamCaption}\item[{void}]{}{}\end{DoxyParamCaption})}

\Hypertarget{i2c1__driver_8c_a9f9b3eb668f0806c719c4d5e8f78089f}\index{i2c1\_driver.c@{i2c1\_driver.c}!i2c1\_driver\_Slavei2cISR@{i2c1\_driver\_Slavei2cISR}}
\index{i2c1\_driver\_Slavei2cISR@{i2c1\_driver\_Slavei2cISR}!i2c1\_driver.c@{i2c1\_driver.c}}
\doxysubsubsection{\texorpdfstring{i2c1\_driver\_Slavei2cISR}{i2c1\_driver\_Slavei2cISR}}
{\footnotesize\ttfamily \label{i2c1__driver_8c_a9f9b3eb668f0806c719c4d5e8f78089f} 
void(\texorpdfstring{$\ast$}{*} i2c1\+\_\+driver\+\_\+\+Slavei2c\+ISR) (void) (\begin{DoxyParamCaption}\item[{void}]{}{}\end{DoxyParamCaption})}

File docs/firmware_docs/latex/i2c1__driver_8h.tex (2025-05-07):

\doxysection{color\+\_\+sensor/i2c1\+\_\+driver.h File Reference}
\hypertarget{i2c1__driver_8h}{}\label{i2c1__driver_8h}\index{color\_sensor/i2c1\_driver.h@{color\_sensor/i2c1\_driver.h}}

I2C driver header.  

{\ttfamily \#include $<$stdio.\+h$>$}\newline
{\ttfamily \#include $<$stdint.\+h$>$}\newline
{\ttfamily \#include $<$stdbool.\+h$>$}\newline
\doxysubsubsection*{Typedefs}
\begin{DoxyCompactItemize}
\item 
typedef void(\texorpdfstring{$\ast$}{*} \mbox{\hyperlink{i2c1__driver_8h_a397ac9a93480802dfb9e14e4af73e767}{interrupt\+Handler}}) (void)
\end{DoxyCompactItemize}
\doxysubsubsection*{Functions}
\begin{DoxyCompactItemize}
\item 
void \mbox{\hyperlink{i2c1__driver_8h_aff5fb84305b4e5655721c950a3488196}{i2c1\+\_\+driver\+\_\+close}} (void)
\begin{DoxyCompactList}\small\item\em Disables the I2\+C1 peripheral by clearing the enable bit. \end{DoxyCompactList}\item 
void \mbox{\hyperlink{i2c1__driver_8h_a8ef15a19099711e8ee10fd31a7d7b847}{i2c1\+\_\+enable\+IRQ}} (void)
\begin{DoxyCompactList}\small\item\em Enables the I2\+C1 master and slave interrupt sources. \end{DoxyCompactList}\item 
bool \mbox{\hyperlink{i2c1__driver_8h_a3a562d793c89fe5f86c8954605041f1f}{i2c1\+\_\+\+IRQis\+Enabled}} (void)
\begin{DoxyCompactList}\small\item\em Checks whether I2\+C1 interrupts are currently enabled. \end{DoxyCompactList}\item 
void \mbox{\hyperlink{i2c1__driver_8h_ad88ed6deb0c925a79b507f0eced17c38}{i2c1\+\_\+disable\+IRQ}} (void)
\begin{DoxyCompactList}\small\item\em Disables the I2\+C1 master and slave interrupt sources. \end{DoxyCompactList}\item 
void \mbox{\hyperlink{i2c1__driver_8h_a33f284f52c97edb7125db041f382b98e}{i2c1\+\_\+clear\+IRQ}} (void)
\begin{DoxyCompactList}\small\item\em Clears the I2\+C1 interrupt flags. \end{DoxyCompactList}\item 
void \mbox{\hyperlink{i2c1__driver_8h_a733a1bea54d71551298a6780208796c9}{i2c1\+\_\+set\+IRQ}} (void)
\begin{DoxyCompactList}\small\item\em Sets the I2\+C1 interrupt flags. \end{DoxyCompactList}\item 
void \mbox{\hyperlink{i2c1__driver_8h_ae5cddc4b1527423f7d4b697326b0e8b3}{i2c1\+\_\+wait\+For\+Event}} (uint16\+\_\+t \texorpdfstring{$\ast$}{*})
\begin{DoxyCompactList}\small\item\em Waits for an I2\+C1 interrupt event with an optional timeout. \end{DoxyCompactList}\item 
bool \mbox{\hyperlink{i2c1__driver_8h_a73e12d1ac2f9ed036a413a4ec4973512}{i2c1\+\_\+driver\+\_\+driver\+\_\+open}} (void)
\begin{DoxyCompactList}\small\item\em Opens the I2\+C1 driver and initializes the hardware. \end{DoxyCompactList}\item 
char \mbox{\hyperlink{i2c1__driver_8h_ac99db9ea0d028200180c594b863fb6b0}{i2c1\+\_\+driver\+\_\+get\+RXData}} (void)
\begin{DoxyCompactList}\small\item\em Reads a received byte of data from I2\+C1. \end{DoxyCompactList}\item 
void \mbox{\hyperlink{i2c1__driver_8h_acfa3b364ea251fef22f8530f1dabe12d}{i2c1\+\_\+driver\+\_\+\+TXData}} (uint8\+\_\+t)
\begin{DoxyCompactList}\small\item\em Transmits a byte of data over I2\+C1. \end{DoxyCompactList}\item 
void \mbox{\hyperlink{i2c1__driver_8h_a3291584a36361a8b886a5565a0897474}{i2c1\+\_\+driver\+\_\+reset\+Bus}} (void)
\begin{DoxyCompactList}\small\item\em Resets the I2\+C1 bus. \end{DoxyCompactList}\item 
void \mbox{\hyperlink{i2c1__driver_8h_a826f86a40e425c0280cac832497d48f1}{i2c1\+\_\+driver\+\_\+start}} (void)
\begin{DoxyCompactList}\small\item\em Starts a new I2\+C1 communication. \end{DoxyCompactList}\item 
void \mbox{\hyperlink{i2c1__driver_8h_a9417c263829b30c425f14cd5576b4f44}{i2c1\+\_\+driver\+\_\+restart}} (void)
\begin{DoxyCompactList}\small\item\em Sends a restart condition on I2\+C1 bus. \end{DoxyCompactList}\item 
void \mbox{\hyperlink{i2c1__driver_8h_a822b30de8bc66d6a5dd767066497ad87}{i2c1\+\_\+driver\+\_\+stop}} (void)
\begin{DoxyCompactList}\small\item\em Sends a stop condition on I2\+C1 bus. \end{DoxyCompactList}\item 
bool \mbox{\hyperlink{i2c1__driver_8h_a35f6f9da194842280debb04be644c373}{i2c1\+\_\+driver\+\_\+is\+NACK}} (void)
\begin{DoxyCompactList}\small\item\em Checks if the last I2\+C1 operation was a NACK (Not Acknowledge). \end{DoxyCompactList}\item 
void \mbox{\hyperlink{i2c1__driver_8h_a0c0e213e454c56ad73d3eb1daa66dbec}{i2c1\+\_\+driver\+\_\+start\+RX}} (void)
\begin{DoxyCompactList}\small\item\em Starts receiving data on I2\+C1. \end{DoxyCompactList}\item 
void \mbox{\hyperlink{i2c1__driver_8h_a7b61d469696ce43586ad65b00fe497c8}{i2c1\+\_\+driver\+\_\+send\+ACK}} (void)
\begin{DoxyCompactList}\small\item\em Sends an ACK (Acknowledge) signal on the I2\+C1 bus. \end{DoxyCompactList}\item 
void \mbox{\hyperlink{i2c1__driver_8h_aee61ef34c048aa4149d15fc7bfba83d0}{i2c1\+\_\+driver\+\_\+send\+NACK}} (void)
\begin{DoxyCompactList}\small\item\em Sends a NACK (Not Acknowledge) signal on the I2\+C1 bus. \end{DoxyCompactList}\item 
void \mbox{\hyperlink{i2c1__driver_8h_a3639e5e0f758d398635ebe19d3e3bfc3}{i2c1\+\_\+driver\+\_\+clear\+Bus\+Collision}} (void)
\begin{DoxyCompactList}\small\item\em Clears the I2\+C1 bus collision flag. \end{DoxyCompactList}\item 
bool \mbox{\hyperlink{i2c1__driver_8h_a0f9e55c5736c1b1fc31d3055093bf997}{i2c1\+\_\+driver\+\_\+init\+Slave\+Hardware}} (void)
\begin{DoxyCompactList}\small\item\em Initializes the I2\+C1 hardware in slave mode. \end{DoxyCompactList}\item 
void \mbox{\hyperlink{i2c1__driver_8h_af08a3c0de397654999ff28878635b84b}{i2c1\+\_\+driver\+\_\+release\+Clock}} (void)
\begin{DoxyCompactList}\small\item\em Releases the I2\+C1 clock. \end{DoxyCompactList}\item 
bool \mbox{\hyperlink{i2c1__driver_8h_af0a6e32e38bd9467f0ece088996bae76}{i2c1\+\_\+driver\+\_\+is\+Bufer\+Full}} (void)
\begin{DoxyCompactList}\small\item\em Checks if the I2\+C1 buffer is full. \end{DoxyCompactList}\item 
bool \mbox{\hyperlink{i2c1__driver_8h_a5e4122ae176771eaca282cce372486bd}{i2c1\+\_\+driver\+\_\+is\+Start}} (void)
\begin{DoxyCompactList}\small\item\em Checks if the I2\+C1 bus is in the start condition. \end{DoxyCompactList}\item 
bool \mbox{\hyperlink{i2c1__driver_8h_a5b2c47d3881ea90cf7f8654b826176f6}{i2c1\+\_\+driver\+\_\+is\+Stop}} (void)
\begin{DoxyCompactList}\small\item\em Checks if the I2\+C1 bus is in the stop condition. \end{DoxyCompactList}\item 
bool \mbox{\hyperlink{i2c1__driver_8h_ae7ec5ac5ff5ad12465ca489d1fcf1bee}{i2c1\+\_\+driver\+\_\+is\+Address}} (void)
\begin{DoxyCompactList}\small\item\em Checks if the current I2\+C1 operation is addressing. \end{DoxyCompactList}\item 
bool \mbox{\hyperlink{i2c1__driver_8h_a3f7cf8eea1e9a6c4fe27584994f1169e}{i2c1\+\_\+driver\+\_\+is\+Data}} (void)
\begin{DoxyCompactList}\small\item\em Checks if the current I2\+C1 operation is data transfer. \end{DoxyCompactList}\item 
bool \mbox{\hyperlink{i2c1__driver_8h_a678cb4a782b2af3024b46c99302b4f02}{i2c1\+\_\+driver\+\_\+is\+Read}} (void)
\begin{DoxyCompactList}\small\item\em Checks if the current I2\+C1 operation is a read. \end{DoxyCompactList}\item 
void \mbox{\hyperlink{i2c1__driver_8h_a77c2d72c9fca24dd43990df49d51ca53}{i2c1\+\_\+driver\+\_\+enable\+Start\+IRQ}} (void)
\begin{DoxyCompactList}\small\item\em Enables the I2\+C1 start condition interrupt. \end{DoxyCompactList}\item 
void \mbox{\hyperlink{i2c1__driver_8h_acbc71e0e45d8c7464e36ce128cfd1e9c}{i2c1\+\_\+driver\+\_\+disable\+Start\+IRQ}} (void)
\begin{DoxyCompactList}\small\item\em Disables the I2\+C1 start condition interrupt. \end{DoxyCompactList}\item 
void \mbox{\hyperlink{i2c1__driver_8h_a4a74f266c1ad5e78e30c92ba898f021c}{i2c1\+\_\+driver\+\_\+enable\+Stop\+IRQ}} (void)
\begin{DoxyCompactList}\small\item\em Enables the I2\+C1 stop condition interrupt. \end{DoxyCompactList}\item 
void \mbox{\hyperlink{i2c1__driver_8h_af2ac828c29858571eeb12a8a768b6eaf}{i2c1\+\_\+driver\+\_\+disable\+Stop\+IRQ}} (void)
\begin{DoxyCompactList}\small\item\em Disables the I2\+C1 stop condition interrupt. \end{DoxyCompactList}\item 
void \mbox{\hyperlink{i2c1__driver_8h_aa907711128fc436c2e7542b32148187c}{i2c1\+\_\+driver\+\_\+set\+Bus\+Collision\+ISR}} (\mbox{\hyperlink{i2c1__driver_8h_a397ac9a93480802dfb9e14e4af73e767}{interrupt\+Handler}} handler)
\begin{DoxyCompactList}\small\item\em Sets the interrupt service routine (ISR) for I2\+C1 bus collision. \end{DoxyCompactList}\item 
void \mbox{\hyperlink{i2c1__driver_8h_a406d4d1be058f2358fc613e45db46513}{i2c1\+\_\+driver\+\_\+set\+Master\+I2c\+ISR}} (\mbox{\hyperlink{i2c1__driver_8h_a397ac9a93480802dfb9e14e4af73e767}{interrupt\+Handler}} handler)
\begin{DoxyCompactList}\small\item\em Sets the interrupt service routine (ISR) for I2\+C1 master mode. \end{DoxyCompactList}\item 
void \mbox{\hyperlink{i2c1__driver_8h_aab163b34535ddda4fea4ea0a7cdf5a94}{i2c1\+\_\+driver\+\_\+set\+Slave\+I2c\+ISR}} (\mbox{\hyperlink{i2c1__driver_8h_a397ac9a93480802dfb9e14e4af73e767}{interrupt\+Handler}} handler)
\begin{DoxyCompactList}\small\item\em Sets the interrupt service routine (ISR) for I2\+C1 slave mode. \end{DoxyCompactList}\end{DoxyCompactItemize}

\doxysubsection{Detailed Description}
I2C driver header. 

\doxysubsection{Typedef Documentation}
\Hypertarget{i2c1__driver_8h_a397ac9a93480802dfb9e14e4af73e767}\index{i2c1\_driver.h@{i2c1\_driver.h}!interruptHandler@{interruptHandler}}
\index{interruptHandler@{interruptHandler}!i2c1\_driver.h@{i2c1\_driver.h}}
\doxysubsubsection{\texorpdfstring{interruptHandler}{interruptHandler}}
{\footnotesize\ttfamily \label{i2c1__driver_8h_a397ac9a93480802dfb9e14e4af73e767} 
typedef void(\texorpdfstring{$\ast$}{*} interrupt\+Handler) (void)}

\doxysubsection{Function Documentation}
\Hypertarget{i2c1__driver_8h_a33f284f52c97edb7125db041f382b98e}\index{i2c1\_driver.h@{i2c1\_driver.h}!i2c1\_clearIRQ@{i2c1\_clearIRQ}}
\index{i2c1\_clearIRQ@{i2c1\_clearIRQ}!i2c1\_driver.h@{i2c1\_driver.h}}
\doxysubsubsection{\texorpdfstring{i2c1\_clearIRQ()}{i2c1\_clearIRQ()}}
{\footnotesize\ttfamily \label{i2c1__driver_8h_a33f284f52c97edb7125db041f382b98e} 
void i2c1\+\_\+clear\+IRQ (\begin{DoxyParamCaption}\item[{void}]{}{}\end{DoxyParamCaption})}

Clears the I2\+C1 interrupt flags. 

Resets the master and slave interrupt flags to 0. \Hypertarget{i2c1__driver_8h_ad88ed6deb0c925a79b507f0eced17c38}\index{i2c1\_driver.h@{i2c1\_driver.h}!i2c1\_disableIRQ@{i2c1\_disableIRQ}}
\index{i2c1\_disableIRQ@{i2c1\_disableIRQ}!i2c1\_driver.h@{i2c1\_driver.h}}
\doxysubsubsection{\texorpdfstring{i2c1\_disableIRQ()}{i2c1\_disableIRQ()}}
{\footnotesize\ttfamily \label{i2c1__driver_8h_ad88ed6deb0c925a79b507f0eced17c38} 
void i2c1\+\_\+disable\+IRQ (\begin{DoxyParamCaption}\item[{void}]{}{}\end{DoxyParamCaption})}

Disables the I2\+C1 master and slave interrupt sources. 

Clears the interrupt enable bits for both master and slave I2\+C1 events. \Hypertarget{i2c1__driver_8h_a3639e5e0f758d398635ebe19d3e3bfc3}\index{i2c1\_driver.h@{i2c1\_driver.h}!i2c1\_driver\_clearBusCollision@{i2c1\_driver\_clearBusCollision}}
\index{i2c1\_driver\_clearBusCollision@{i2c1\_driver\_clearBusCollision}!i2c1\_driver.h@{i2c1\_driver.h}}
\doxysubsubsection{\texorpdfstring{i2c1\_driver\_clearBusCollision()}{i2c1\_driver\_clearBusCollision()}}
{\footnotesize\ttfamily \label{i2c1__driver_8h_a3639e5e0f758d398635ebe19d3e3bfc3} 
void i2c1\+\_\+driver\+\_\+clear\+Bus\+Collision (\begin{DoxyParamCaption}\item[{void}]{}{}\end{DoxyParamCaption})}

Clears the I2\+C1 bus collision flag. 

This function clears the Bus Collision (BCL) flag in the I2\+C1\+STAT register. This is necessary after handling a bus collision event to reset the flag. \Hypertarget{i2c1__driver_8h_aff5fb84305b4e5655721c950a3488196}\index{i2c1\_driver.h@{i2c1\_driver.h}!i2c1\_driver\_close@{i2c1\_driver\_close}}
\index{i2c1\_driver\_close@{i2c1\_driver\_close}!i2c1\_driver.h@{i2c1\_driver.h}}
\doxysubsubsection{\texorpdfstring{i2c1\_driver\_close()}{i2c1\_driver\_close()}}
{\footnotesize\ttfamily \label{i2c1__driver_8h_aff5fb84305b4e5655721c950a3488196} 
void i2c1\+\_\+driver\+\_\+close (\begin{DoxyParamCaption}\item[{void}]{}{}\end{DoxyParamCaption})}

Disables the I2\+C1 peripheral by clearing the enable bit. 

This function turns off the I2\+C1 hardware module. \Hypertarget{i2c1__driver_8h_acbc71e0e45d8c7464e36ce128cfd1e9c}\index{i2c1\_driver.h@{i2c1\_driver.h}!i2c1\_driver\_disableStartIRQ@{i2c1\_driver\_disableStartIRQ}}
\index{i2c1\_driver\_disableStartIRQ@{i2c1\_driver\_disableStartIRQ}!i2c1\_driver.h@{i2c1\_driver.h}}
\doxysubsubsection{\texorpdfstring{i2c1\_driver\_disableStartIRQ()}{i2c1\_driver\_disableStartIRQ()}}
{\footnotesize\ttfamily \label{i2c1__driver_8h_acbc71e0e45d8c7464e36ce128cfd1e9c} 
void i2c1\+\_\+driver\+\_\+disable\+Start\+IRQ (\begin{DoxyParamCaption}\item[{void}]{}{}\end{DoxyParamCaption})}

Disables the I2\+C1 start condition interrupt. 

This function disables the interrupt for the start condition detected on the I2\+C1 bus by clearing the SCIE bit in the I2\+C1\+CONH register. This prevents the I2C controller from generating interrupts on the start condition. \Hypertarget{i2c1__driver_8h_af2ac828c29858571eeb12a8a768b6eaf}\index{i2c1\_driver.h@{i2c1\_driver.h}!i2c1\_driver\_disableStopIRQ@{i2c1\_driver\_disableStopIRQ}}
\index{i2c1\_driver\_disableStopIRQ@{i2c1\_driver\_disableStopIRQ}!i2c1\_driver.h@{i2c1\_driver.h}}
\doxysubsubsection{\texorpdfstring{i2c1\_driver\_disableStopIRQ()}{i2c1\_driver\_disableStopIRQ()}}
{\footnotesize\ttfamily \label{i2c1__driver_8h_af2ac828c29858571eeb12a8a768b6eaf} 
void i2c1\+\_\+driver\+\_\+disable\+Stop\+IRQ (\begin{DoxyParamCaption}\item[{void}]{}{}\end{DoxyParamCaption})}

Disables the I2\+C1 stop condition interrupt. 

This function disables the interrupt for the stop condition detected on the I2\+C1 bus by clearing the PCIE bit in the I2\+C1\+CONH register. This prevents the I2C controller from generating interrupts on the stop condition. \Hypertarget{i2c1__driver_8h_a73e12d1ac2f9ed036a413a4ec4973512}\index{i2c1\_driver.h@{i2c1\_driver.h}!i2c1\_driver\_driver\_open@{i2c1\_driver\_driver\_open}}
\index{i2c1\_driver\_driver\_open@{i2c1\_driver\_driver\_open}!i2c1\_driver.h@{i2c1\_driver.h}}
\doxysubsubsection{\texorpdfstring{i2c1\_driver\_driver\_open()}{i2c1\_driver\_driver\_open()}}
{\footnotesize\ttfamily \label{i2c1__driver_8h_a73e12d1ac2f9ed036a413a4ec4973512} 
bool i2c1\+\_\+driver\+\_\+driver\+\_\+open (\begin{DoxyParamCaption}\item[{void}]{}{}\end{DoxyParamCaption})}

Opens the I2\+C1 driver and initializes the hardware. 

This function checks if the I2\+C1 module is disabled and, if so, initializes the hardware by configuring control and status registers, setting the baud rate, and enabling the module.

\begin{DoxyReturn}{Returns}
true if the I2\+C1 module was successfully initialized, false if it is already enabled. 
\end{DoxyReturn}
\Hypertarget{i2c1__driver_8h_a77c2d72c9fca24dd43990df49d51ca53}\index{i2c1\_driver.h@{i2c1\_driver.h}!i2c1\_driver\_enableStartIRQ@{i2c1\_driver\_enableStartIRQ}}
\index{i2c1\_driver\_enableStartIRQ@{i2c1\_driver\_enableStartIRQ}!i2c1\_driver.h@{i2c1\_driver.h}}
\doxysubsubsection{\texorpdfstring{i2c1\_driver\_enableStartIRQ()}{i2c1\_driver\_enableStartIRQ()}}
{\footnotesize\ttfamily \label{i2c1__driver_8h_a77c2d72c9fca24dd43990df49d51ca53} 
void i2c1\+\_\+driver\+\_\+enable\+Start\+IRQ (\begin{DoxyParamCaption}\item[{void}]{}{}\end{DoxyParamCaption})}

Enables the I2\+C1 start condition interrupt. 

This function enables the interrupt for the start condition detected on the I2\+C1 bus by setting the SCIE bit in the I2\+C1\+CONH register. When this interrupt is enabled, the I2C controller will generate an interrupt on the start condition. \Hypertarget{i2c1__driver_8h_a4a74f266c1ad5e78e30c92ba898f021c}\index{i2c1\_driver.h@{i2c1\_driver.h}!i2c1\_driver\_enableStopIRQ@{i2c1\_driver\_enableStopIRQ}}
\index{i2c1\_driver\_enableStopIRQ@{i2c1\_driver\_enableStopIRQ}!i2c1\_driver.h@{i2c1\_driver.h}}
\doxysubsubsection{\texorpdfstring{i2c1\_driver\_enableStopIRQ()}{i2c1\_driver\_enableStopIRQ()}}
{\footnotesize\ttfamily \label{i2c1__driver_8h_a4a74f266c1ad5e78e30c92ba898f021c} 
void i2c1\+\_\+driver\+\_\+enable\+Stop\+IRQ (\begin{DoxyParamCaption}\item[{void}]{}{}\end{DoxyParamCaption})}

Enables the I2\+C1 stop condition interrupt. 

This function enables the interrupt for the stop condition detected on the I2\+C1 bus by setting the PCIE bit in the I2\+C1\+CONH register. When this interrupt is enabled, the I2C controller will generate an interrupt on the stop condition. \Hypertarget{i2c1__driver_8h_ac99db9ea0d028200180c594b863fb6b0}\index{i2c1\_driver.h@{i2c1\_driver.h}!i2c1\_driver\_getRXData@{i2c1\_driver\_getRXData}}
\index{i2c1\_driver\_getRXData@{i2c1\_driver\_getRXData}!i2c1\_driver.h@{i2c1\_driver.h}}
\doxysubsubsection{\texorpdfstring{i2c1\_driver\_getRXData()}{i2c1\_driver\_getRXData()}}
{\footnotesize\ttfamily \label{i2c1__driver_8h_ac99db9ea0d028200180c594b863fb6b0} 
char i2c1\+\_\+driver\+\_\+get\+RXData (\begin{DoxyParamCaption}\item[{void}]{}{}\end{DoxyParamCaption})}

Reads a received byte of data from I2\+C1. 

This function retrieves the received data from the I2\+C1\+RCV register after enabling the RX mode.

\begin{DoxyReturn}{Returns}
The byte of data received on the I2\+C1 bus. 
\end{DoxyReturn}
\Hypertarget{i2c1__driver_8h_a0f9e55c5736c1b1fc31d3055093bf997}\index{i2c1\_driver.h@{i2c1\_driver.h}!i2c1\_driver\_initSlaveHardware@{i2c1\_driver\_initSlaveHardware}}
\index{i2c1\_driver\_initSlaveHardware@{i2c1\_driver\_initSlaveHardware}!i2c1\_driver.h@{i2c1\_driver.h}}
\doxysubsubsection{\texorpdfstring{i2c1\_driver\_initSlaveHardware()}{i2c1\_driver\_initSlaveHardware()}}
{\footnotesize\ttfamily \label{i2c1__driver_8h_a0f9e55c5736c1b1fc31d3055093bf997} 
bool i2c1\+\_\+driver\+\_\+init\+Slave\+Hardware (\begin{DoxyParamCaption}\item[{void}]{}{}\end{DoxyParamCaption})}

Initializes the I2\+C1 hardware in slave mode. 

This function configures the I2\+C1 module for slave operation by enabling the address and data hold features and setting the strength of the slave pull-\/ups. The module is then enabled.

\begin{DoxyReturn}{Returns}
true if the I2\+C1 module was successfully initialized in slave mode, false if the module is already enabled. 
\end{DoxyReturn}
\Hypertarget{i2c1__driver_8h_ae7ec5ac5ff5ad12465ca489d1fcf1bee}\index{i2c1\_driver.h@{i2c1\_driver.h}!i2c1\_driver\_isAddress@{i2c1\_driver\_isAddress}}
\index{i2c1\_driver\_isAddress@{i2c1\_driver\_isAddress}!i2c1\_driver.h@{i2c1\_driver.h}}
\doxysubsubsection{\texorpdfstring{i2c1\_driver\_isAddress()}{i2c1\_driver\_isAddress()}}
{\footnotesize\ttfamily \label{i2c1__driver_8h_ae7ec5ac5ff5ad12465ca489d1fcf1bee} 
bool i2c1\+\_\+driver\+\_\+is\+Address (\begin{DoxyParamCaption}\item[{void}]{}{}\end{DoxyParamCaption})}

Checks if the current I2\+C1 operation is addressing. 

This function checks the value of the D\+\_\+A bit in the I2\+C1\+STAT register. If D\+\_\+A is 0, it indicates that the current I2C operation is addressing, meaning that the master is addressing the slave device.

\begin{DoxyReturn}{Returns}
true if the current operation is addressing, false otherwise. 
\end{DoxyReturn}
\Hypertarget{i2c1__driver_8h_af0a6e32e38bd9467f0ece088996bae76}\index{i2c1\_driver.h@{i2c1\_driver.h}!i2c1\_driver\_isBuferFull@{i2c1\_driver\_isBuferFull}}
\index{i2c1\_driver\_isBuferFull@{i2c1\_driver\_isBuferFull}!i2c1\_driver.h@{i2c1\_driver.h}}
\doxysubsubsection{\texorpdfstring{i2c1\_driver\_isBuferFull()}{i2c1\_driver\_isBuferFull()}}
{\footnotesize\ttfamily \label{i2c1__driver_8h_af0a6e32e38bd9467f0ece088996bae76} 
bool i2c1\+\_\+driver\+\_\+is\+Bufer\+Full (\begin{DoxyParamCaption}\item[{void}]{}{}\end{DoxyParamCaption})}

Checks if the I2\+C1 buffer is full. 

This function checks if either the receive buffer (RBF) or transmit buffer (TBF) in the I2\+C1\+STAT register is full, indicating that data is ready to be read or written.

\begin{DoxyReturn}{Returns}
true if the buffer is full, false otherwise. 
\end{DoxyReturn}
\Hypertarget{i2c1__driver_8h_a3f7cf8eea1e9a6c4fe27584994f1169e}\index{i2c1\_driver.h@{i2c1\_driver.h}!i2c1\_driver\_isData@{i2c1\_driver\_isData}}
\index{i2c1\_driver\_isData@{i2c1\_driver\_isData}!i2c1\_driver.h@{i2c1\_driver.h}}
\doxysubsubsection{\texorpdfstring{i2c1\_driver\_isData()}{i2c1\_driver\_isData()}}
{\footnotesize\ttfamily \label{i2c1__driver_8h_a3f7cf8eea1e9a6c4fe27584994f1169e} 
bool i2c1\+\_\+driver\+\_\+is\+Data (\begin{DoxyParamCaption}\item[{void}]{}{}\end{DoxyParamCaption})}

Checks if the current I2\+C1 operation is data transfer. 

This function checks the value of the D\+\_\+A bit in the I2\+C1\+STAT register. If D\+\_\+A is 1, it indicates that the current operation is data transfer, meaning that the I2C bus is currently transferring data (not addressing).

\begin{DoxyReturn}{Returns}
true if the current operation is data transfer, false otherwise. 
\end{DoxyReturn}
\Hypertarget{i2c1__driver_8h_a35f6f9da194842280debb04be644c373}\index{i2c1\_driver.h@{i2c1\_driver.h}!i2c1\_driver\_isNACK@{i2c1\_driver\_isNACK}}
\index{i2c1\_driver\_isNACK@{i2c1\_driver\_isNACK}!i2c1\_driver.h@{i2c1\_driver.h}}
\doxysubsubsection{\texorpdfstring{i2c1\_driver\_isNACK()}{i2c1\_driver\_isNACK()}}
{\footnotesize\ttfamily \label{i2c1__driver_8h_a35f6f9da194842280debb04be644c373} 
bool i2c1\+\_\+driver\+\_\+is\+NACK (\begin{DoxyParamCaption}\item[{void}]{}{}\end{DoxyParamCaption})}

Checks if the last I2\+C1 operation was a NACK (Not Acknowledge). 

This function checks the ACKSTAT bit in the I2\+C1\+STAT register to determine whether the last transmission was acknowledged by the slave.

\begin{DoxyReturn}{Returns}
true if a NACK was received, false otherwise. 
\end{DoxyReturn}
\Hypertarget{i2c1__driver_8h_a678cb4a782b2af3024b46c99302b4f02}\index{i2c1\_driver.h@{i2c1\_driver.h}!i2c1\_driver\_isRead@{i2c1\_driver\_isRead}}
\index{i2c1\_driver\_isRead@{i2c1\_driver\_isRead}!i2c1\_driver.h@{i2c1\_driver.h}}
\doxysubsubsection{\texorpdfstring{i2c1\_driver\_isRead()}{i2c1\_driver\_isRead()}}
{\footnotesize\ttfamily \label{i2c1__driver_8h_a678cb4a782b2af3024b46c99302b4f02} 
bool i2c1\+\_\+driver\+\_\+is\+Read (\begin{DoxyParamCaption}\item[{void}]{}{}\end{DoxyParamCaption})}

Checks if the current I2\+C1 operation is a read. 

This function checks the value of the R\+\_\+W bit in the I2\+C1\+STAT register. If R\+\_\+W is 1, it indicates that the current operation is a read operation, meaning that the master is reading data from the slave device.

\begin{DoxyReturn}{Returns}
true if the current operation is a read, false if it is a write. 
\end{DoxyReturn}
\Hypertarget{i2c1__driver_8h_a5e4122ae176771eaca282cce372486bd}\index{i2c1\_driver.h@{i2c1\_driver.h}!i2c1\_driver\_isStart@{i2c1\_driver\_isStart}}
\index{i2c1\_driver\_isStart@{i2c1\_driver\_isStart}!i2c1\_driver.h@{i2c1\_driver.h}}
\doxysubsubsection{\texorpdfstring{i2c1\_driver\_isStart()}{i2c1\_driver\_isStart()}}
{\footnotesize\ttfamily \label{i2c1__driver_8h_a5e4122ae176771eaca282cce372486bd} 
bool i2c1\+\_\+driver\+\_\+is\+Start (\begin{DoxyParamCaption}\item[{void}]{}{}\end{DoxyParamCaption})}

Checks if the I2\+C1 bus is in the start condition. 

This function checks the value of the S bit in the I2\+C1\+STAT register to determine if the I2C bus is currently in the start condition (S). This bit is set when a start condition is detected on the bus.

\begin{DoxyReturn}{Returns}
true if the bus is in the start condition, false otherwise. 
\end{DoxyReturn}
\Hypertarget{i2c1__driver_8h_a5b2c47d3881ea90cf7f8654b826176f6}\index{i2c1\_driver.h@{i2c1\_driver.h}!i2c1\_driver\_isStop@{i2c1\_driver\_isStop}}
\index{i2c1\_driver\_isStop@{i2c1\_driver\_isStop}!i2c1\_driver.h@{i2c1\_driver.h}}
\doxysubsubsection{\texorpdfstring{i2c1\_driver\_isStop()}{i2c1\_driver\_isStop()}}
{\footnotesize\ttfamily \label{i2c1__driver_8h_a5b2c47d3881ea90cf7f8654b826176f6} 
bool i2c1\+\_\+driver\+\_\+is\+Stop (\begin{DoxyParamCaption}\item[{void}]{}{}\end{DoxyParamCaption})}

Checks if the I2\+C1 bus is in the stop condition. 

This function checks the value of the P bit in the I2\+C1\+STAT register to determine if the bus is currently in the stop condition (P), which indicates the end of a communication.

\begin{DoxyReturn}{Returns}
true if the bus is in the stop condition, false otherwise. 
\end{DoxyReturn}
\Hypertarget{i2c1__driver_8h_af08a3c0de397654999ff28878635b84b}\index{i2c1\_driver.h@{i2c1\_driver.h}!i2c1\_driver\_releaseClock@{i2c1\_driver\_releaseClock}}
\index{i2c1\_driver\_releaseClock@{i2c1\_driver\_releaseClock}!i2c1\_driver.h@{i2c1\_driver.h}}
\doxysubsubsection{\texorpdfstring{i2c1\_driver\_releaseClock()}{i2c1\_driver\_releaseClock()}}
{\footnotesize\ttfamily \label{i2c1__driver_8h_af08a3c0de397654999ff28878635b84b} 
void i2c1\+\_\+driver\+\_\+release\+Clock (\begin{DoxyParamCaption}\item[{void}]{}{}\end{DoxyParamCaption})}

Releases the I2\+C1 clock. 

This function sets the SCLREL bit in the I2\+C1\+CONL register to release the I2\+C1 clock. It is used to free the clock if it has been held by the I2C controller. \Hypertarget{i2c1__driver_8h_a3291584a36361a8b886a5565a0897474}\index{i2c1\_driver.h@{i2c1\_driver.h}!i2c1\_driver\_resetBus@{i2c1\_driver\_resetBus}}
\index{i2c1\_driver\_resetBus@{i2c1\_driver\_resetBus}!i2c1\_driver.h@{i2c1\_driver.h}}
\doxysubsubsection{\texorpdfstring{i2c1\_driver\_resetBus()}{i2c1\_driver\_resetBus()}}
{\footnotesize\ttfamily \label{i2c1__driver_8h_a3291584a36361a8b886a5565a0897474} 
void i2c1\+\_\+driver\+\_\+reset\+Bus (\begin{DoxyParamCaption}\item[{void}]{}{}\end{DoxyParamCaption})}

Resets the I2\+C1 bus. 

This function is intended to reset the I2C bus, but it is currently not implemented. \Hypertarget{i2c1__driver_8h_a9417c263829b30c425f14cd5576b4f44}\index{i2c1\_driver.h@{i2c1\_driver.h}!i2c1\_driver\_restart@{i2c1\_driver\_restart}}
\index{i2c1\_driver\_restart@{i2c1\_driver\_restart}!i2c1\_driver.h@{i2c1\_driver.h}}
\doxysubsubsection{\texorpdfstring{i2c1\_driver\_restart()}{i2c1\_driver\_restart()}}
{\footnotesize\ttfamily \label{i2c1__driver_8h_a9417c263829b30c425f14cd5576b4f44} 
void i2c1\+\_\+driver\+\_\+restart (\begin{DoxyParamCaption}\item[{void}]{}{}\end{DoxyParamCaption})}

Sends a restart condition on I2\+C1 bus. 

This function generates a restart condition (RSEN) to resume communication with the slave device without releasing the bus. \Hypertarget{i2c1__driver_8h_a7b61d469696ce43586ad65b00fe497c8}\index{i2c1\_driver.h@{i2c1\_driver.h}!i2c1\_driver\_sendACK@{i2c1\_driver\_sendACK}}
\index{i2c1\_driver\_sendACK@{i2c1\_driver\_sendACK}!i2c1\_driver.h@{i2c1\_driver.h}}
\doxysubsubsection{\texorpdfstring{i2c1\_driver\_sendACK()}{i2c1\_driver\_sendACK()}}
{\footnotesize\ttfamily \label{i2c1__driver_8h_a7b61d469696ce43586ad65b00fe497c8} 
void i2c1\+\_\+driver\+\_\+send\+ACK (\begin{DoxyParamCaption}\item[{void}]{}{}\end{DoxyParamCaption})}

Sends an ACK (Acknowledge) signal on the I2\+C1 bus. 

This function sets the ACKDT bit to 0 and enables the ACKEN bit to initiate the transmission of an ACK signal to the slave device. \Hypertarget{i2c1__driver_8h_aee61ef34c048aa4149d15fc7bfba83d0}\index{i2c1\_driver.h@{i2c1\_driver.h}!i2c1\_driver\_sendNACK@{i2c1\_driver\_sendNACK}}
\index{i2c1\_driver\_sendNACK@{i2c1\_driver\_sendNACK}!i2c1\_driver.h@{i2c1\_driver.h}}
\doxysubsubsection{\texorpdfstring{i2c1\_driver\_sendNACK()}{i2c1\_driver\_sendNACK()}}
{\footnotesize\ttfamily \label{i2c1__driver_8h_aee61ef34c048aa4149d15fc7bfba83d0} 
void i2c1\+\_\+driver\+\_\+send\+NACK (\begin{DoxyParamCaption}\item[{void}]{}{}\end{DoxyParamCaption})}

Sends a NACK (Not Acknowledge) signal on the I2\+C1 bus. 

This function sets the ACKDT bit to 1 and enables the ACKEN bit to initiate the transmission of a NACK signal to the slave device. \Hypertarget{i2c1__driver_8h_aa907711128fc436c2e7542b32148187c}\index{i2c1\_driver.h@{i2c1\_driver.h}!i2c1\_driver\_setBusCollisionISR@{i2c1\_driver\_setBusCollisionISR}}
\index{i2c1\_driver\_setBusCollisionISR@{i2c1\_driver\_setBusCollisionISR}!i2c1\_driver.h@{i2c1\_driver.h}}
\doxysubsubsection{\texorpdfstring{i2c1\_driver\_setBusCollisionISR()}{i2c1\_driver\_setBusCollisionISR()}}
{\footnotesize\ttfamily \label{i2c1__driver_8h_aa907711128fc436c2e7542b32148187c} 
void i2c1\+\_\+driver\+\_\+set\+Bus\+Collision\+ISR (\begin{DoxyParamCaption}\item[{\mbox{\hyperlink{i2c1__driver_8h_a397ac9a93480802dfb9e14e4af73e767}{interrupt\+Handler}}}]{handler}{}\end{DoxyParamCaption})}

Sets the interrupt service routine (ISR) for I2\+C1 bus collision. 

This function allows the user to set a custom interrupt handler for bus collision events on the I2\+C1 bus. The handler is called when a bus collision occurs.

\begin{DoxyParams}{Parameters}
{\em handler} & The interrupt handler function to be set for the bus collision ISR. \\
\hline
\end{DoxyParams}
\Hypertarget{i2c1__driver_8h_a406d4d1be058f2358fc613e45db46513}\index{i2c1\_driver.h@{i2c1\_driver.h}!i2c1\_driver\_setMasterI2cISR@{i2c1\_driver\_setMasterI2cISR}}
\index{i2c1\_driver\_setMasterI2cISR@{i2c1\_driver\_setMasterI2cISR}!i2c1\_driver.h@{i2c1\_driver.h}}
\doxysubsubsection{\texorpdfstring{i2c1\_driver\_setMasterI2cISR()}{i2c1\_driver\_setMasterI2cISR()}}
{\footnotesize\ttfamily \label{i2c1__driver_8h_a406d4d1be058f2358fc613e45db46513} 
void i2c1\+\_\+driver\+\_\+set\+Master\+I2c\+ISR (\begin{DoxyParamCaption}\item[{\mbox{\hyperlink{i2c1__driver_8h_a397ac9a93480802dfb9e14e4af73e767}{interrupt\+Handler}}}]{handler}{}\end{DoxyParamCaption})}

Sets the interrupt service routine (ISR) for I2\+C1 master mode. 

This function allows the user to set a custom interrupt handler for master mode events on the I2\+C1 bus. The handler is called when the I2\+C1 controller is in master mode and the interrupt is triggered.
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

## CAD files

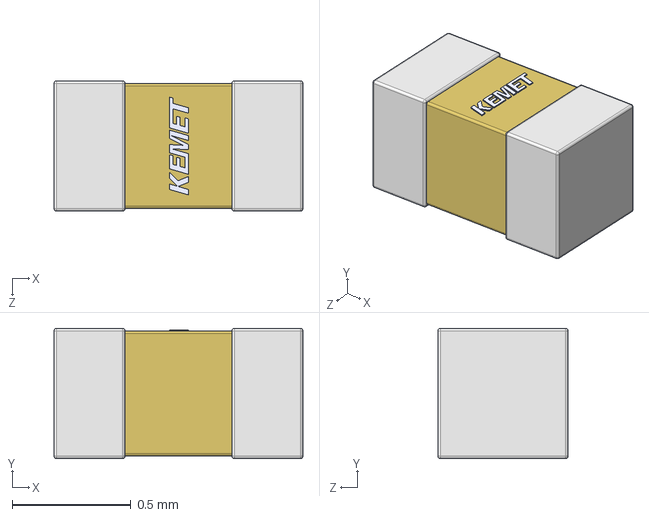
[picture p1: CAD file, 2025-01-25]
pcb_design/kicad_schematics/models/C_Ceramic-100nF/3D/C0402C104M4PACTU.stp
1.05 x 0.55 x 0.55 mm

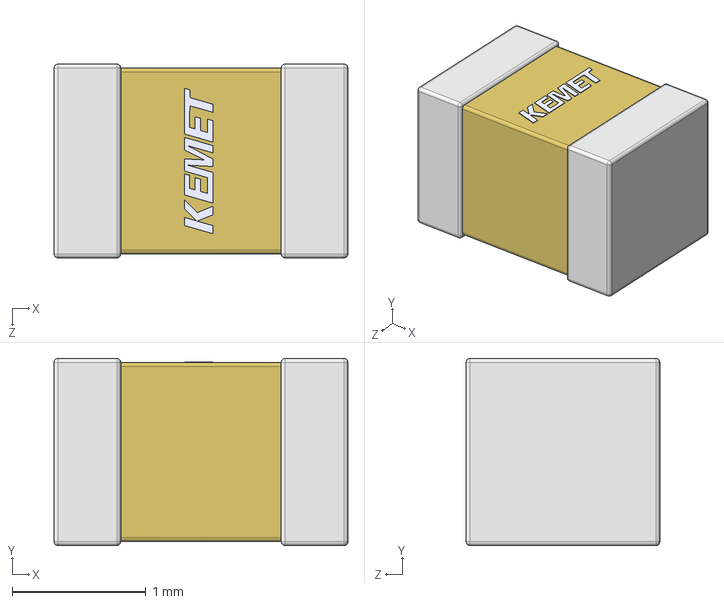
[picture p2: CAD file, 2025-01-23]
pcb_design/kicad_schematics/models/C_Ceramic-10uF/3D/C0805C106M4PACTU.stp
2.20 x 1.40 x 1.45 mm

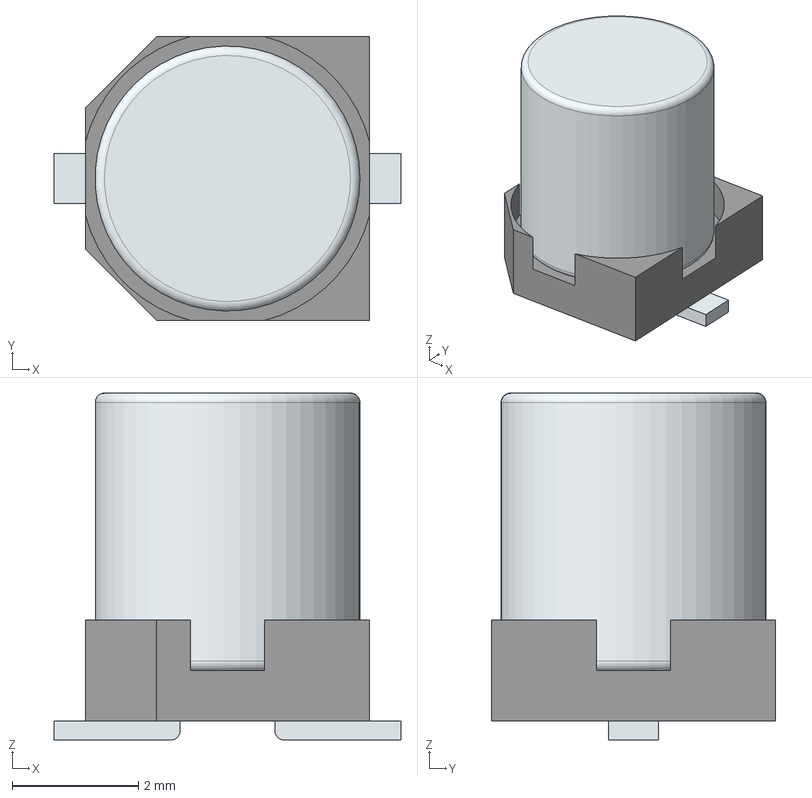
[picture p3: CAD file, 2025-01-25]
pcb_design/kicad_schematics/models/C_Electrolytic_0.1uF/3D/UWP1H0R1MCL1GB.stp
5.50 x 4.50 x 5.50 mm
Base
Pin1Fillet
Pin2Fillet

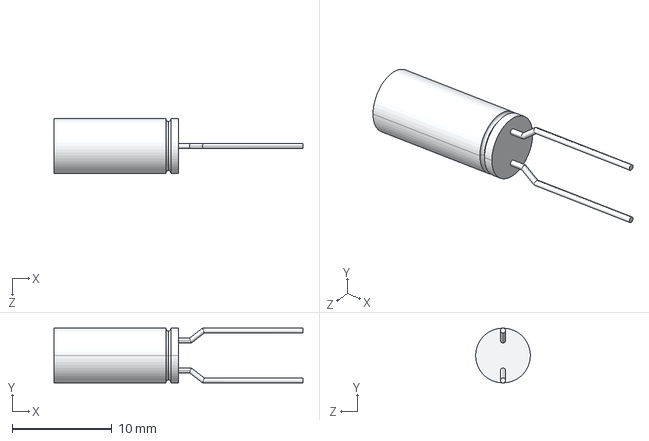
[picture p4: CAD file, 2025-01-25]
pcb_design/kicad_schematics/models/C_Electrolytic_10uF/3D/ESK106M050AC3DA.stp
25.0 x 5.50 x 5.50 mm

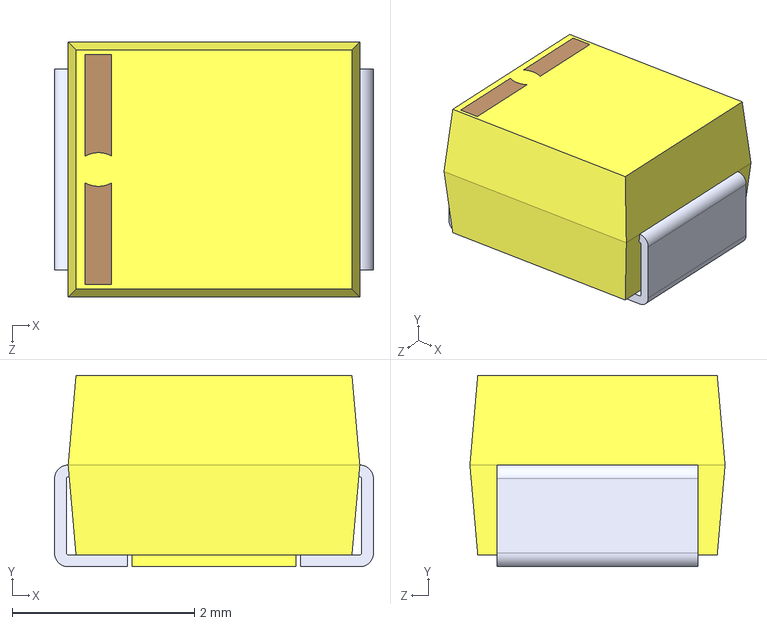
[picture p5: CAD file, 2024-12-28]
pcb_design/kicad_schematics/models/C_Polarized_Tantalum-10uF/T495B106K025ATE750.step
3.50 x 2.10 x 2.80 mm

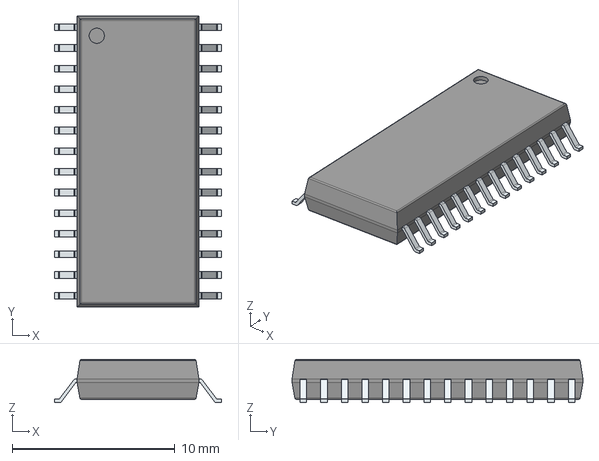
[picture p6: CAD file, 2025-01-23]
pcb_design/kicad_schematics/models/Microcontroller-PIC24FJ64GA702-I_SO/3D/PIC24FJ64GA702-I_SO.stp
10.3 x 17.9 x 2.65 mm
PinsArrayLR

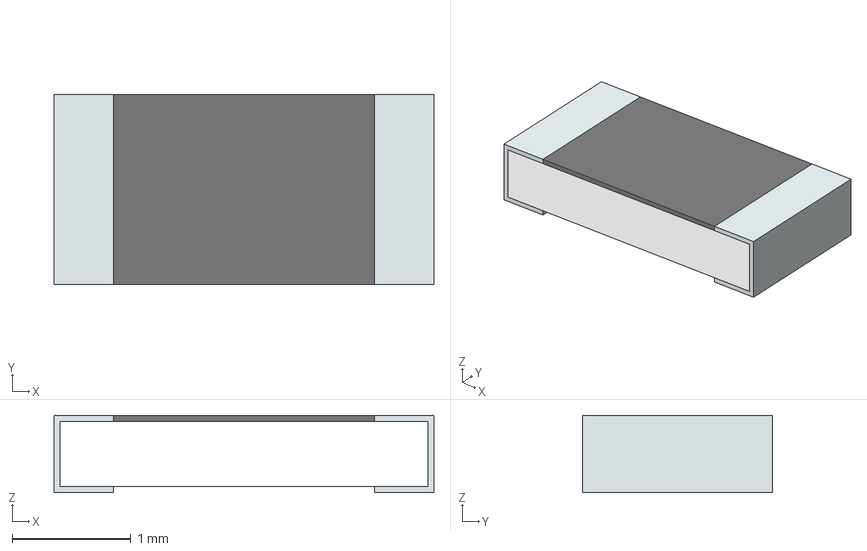
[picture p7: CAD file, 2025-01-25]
pcb_design/kicad_schematics/models/R_SMD_10kOhm/3D/ERA-8VRB1002V.stp
3.20 x 1.60 x 0.65 mm
solidBody
Terminal
solidLid

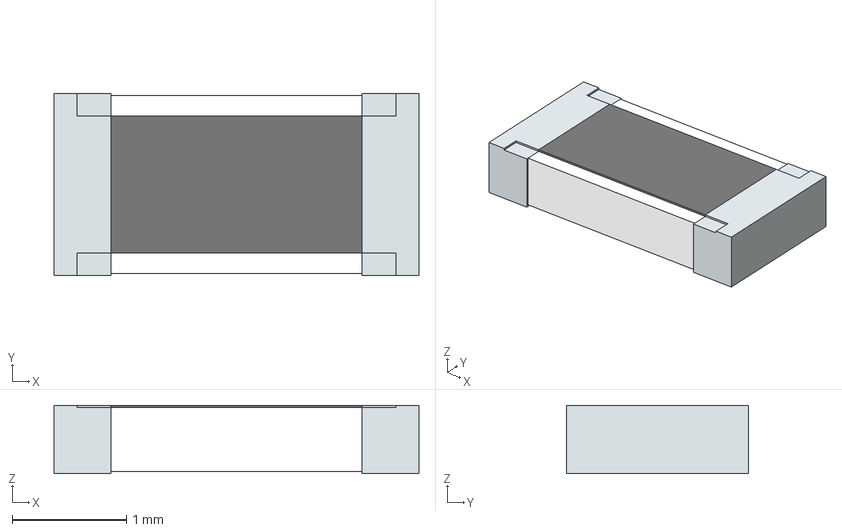
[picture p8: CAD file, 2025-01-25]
pcb_design/kicad_schematics/models/R_SMD_200Ohm/3D/ERA-8AEB201V.stp
3.20 x 1.60 x 0.6 mm
solidBody
Terminal
solidTop

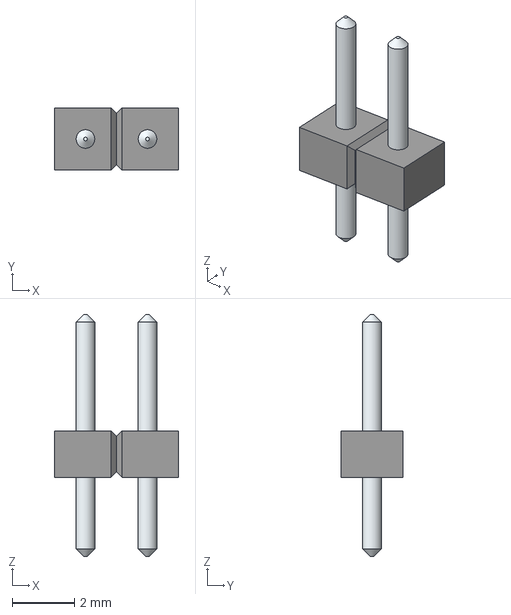
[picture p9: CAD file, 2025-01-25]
pcb_design/kicad_schematics/models/2_pin_Male/3D/M22-2510205.stp
4.00 x 2.00 x 7.80 mm
LeadsArray

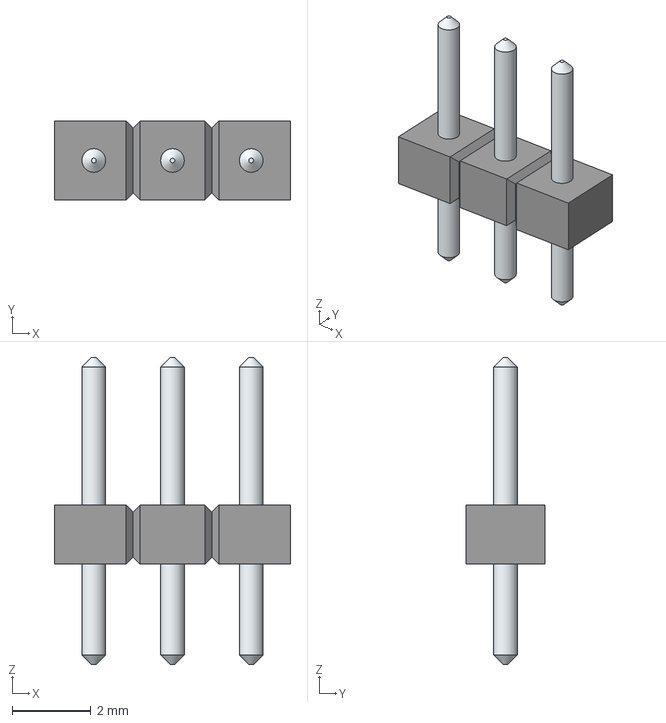
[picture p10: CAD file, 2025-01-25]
pcb_design/kicad_schematics/models/3_pin_Male/3D/M22-2510305.stp
6.00 x 2.00 x 7.80 mm
LeadsArray

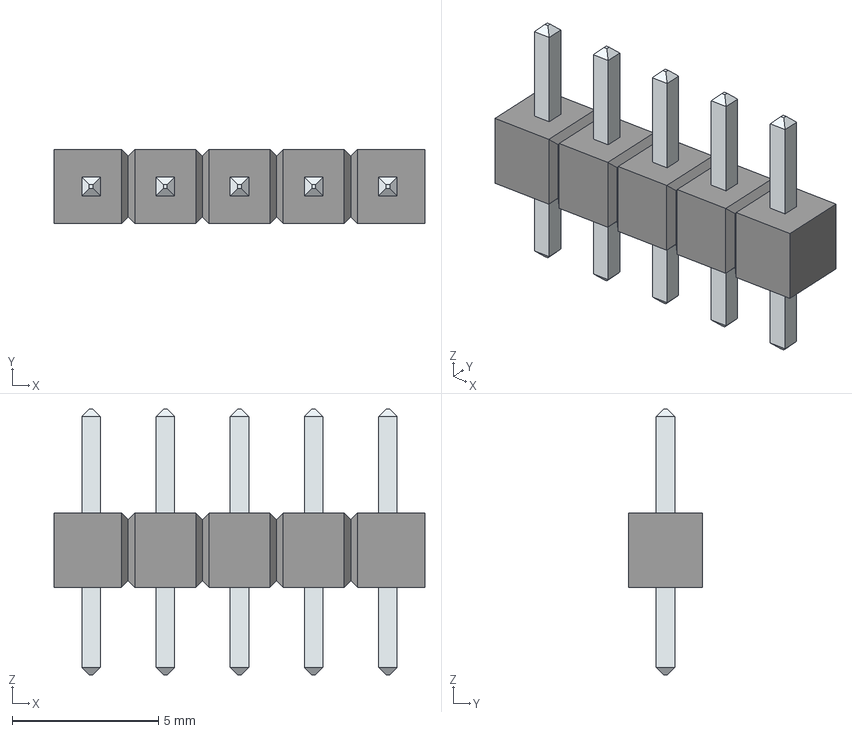
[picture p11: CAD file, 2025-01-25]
pcb_design/kicad_schematics/models/5_pin_Male/3D/M20-9990546.stp
12.7 x 2.54 x 9.10 mm
LeadsArray

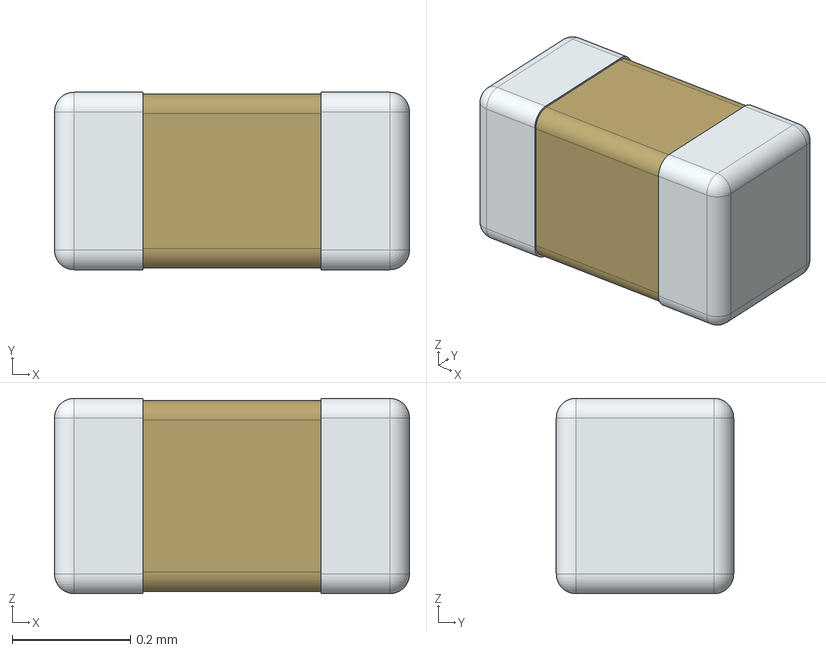
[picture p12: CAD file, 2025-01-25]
pcb_design/kicad_schematics/models/C_Ceramic-10pF/3D/02013A100JAT2A.stp
0.6 x 0.3 x 0.33 mm

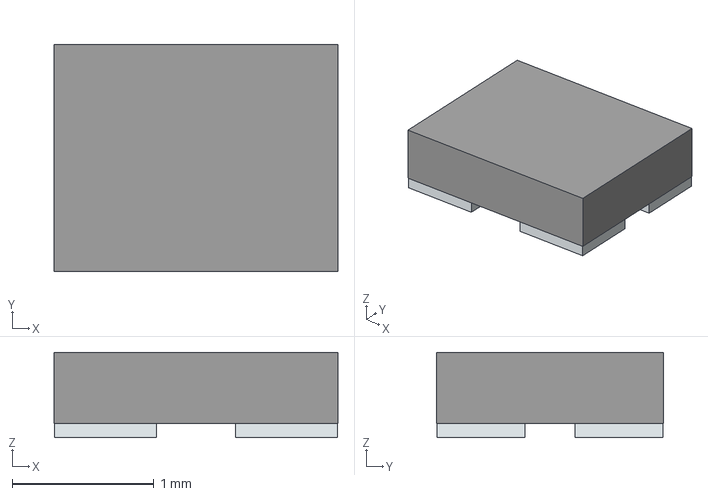
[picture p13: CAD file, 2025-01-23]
pcb_design/kicad_schematics/models/Crystal-830108288709/3D/830108288709.stp
2.00 x 1.60 x 0.6 mm
Pins

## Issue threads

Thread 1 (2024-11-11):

Pronalazak komponenata koje nedostaju

thewantedboss, 2024-11-11:
Trenutna lista komponenata:

- ace tracking sensor
- the steering gear (micro Servo 9g SG90)
- Red LED
- battery case
- HS-Key1B (key module)

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

Potreno je sljedeće:
Za realizaciju projekta Colour-Sorter neophodno je dopuniti postojeću listu komponenti dodatnim dijelovima koji će omogućiti detekciju boja.

thewantedboss, 2024-11-14:
Ocjena je 4.

AndjelaS997, 2024-11-14:
Ocjena  je 5.

GeneralKenobi72, 2024-11-15:
Ocjena 5

GeneralKenobi72, 2024-11-16:
Vrijeme izrade: 15 minuta

Closed 2024-11-16.

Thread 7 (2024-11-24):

Analiza Voltage Regulator Pin

thewantedboss, 2024-11-24:
U okviru ovog zadatka potrebno je analizirati Voltage Regulator Pin (VCAP) mikrokontrolera, istražujući njegovu funkciju i značaj za stabilnost naponskog sistema mikrokontrolera. U okviru zadatka, u dokumentaciji je potrebno uključiti odgovarajuće povezivanja ovog pina i objašnjenje njegovog značaja za cjelokupni rad mikrokontrolera.

thewantedboss, 2024-11-24:
Ocjena 3.

AndjelaS997, 2024-11-25:
Ocijena 3.

GeneralKenobi72, 2024-11-26:
Ocjena 4

Closed 2024-11-26.

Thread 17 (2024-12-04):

Dodati Servo motor u KiCAD šemu

GeneralKenobi72, 2024-12-04:
Dokumentovani servo motor SG90 dodati u KiCAD šemu

GeneralKenobi72, 2024-12-04:
Ocjena tezine 5

AndjelaS997, 2024-12-04:
Ocjena 6.

thewantedboss, 2024-12-06:
Ocjena 5.

AndjelaS997, 2024-12-10:
Vrijeme izrade 40min.

Closed 2024-12-10.

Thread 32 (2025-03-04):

Testirati PCB

GeneralKenobi72, 2025-03-04:
Provjeriti da li je sve dobro zalemljeno, da li postoje kratki spojevi, da li su naponi 4.5V i 3.3V tamo gdje trebaju biti itd...

GeneralKenobi72, 2025-03-04:
Ocjena tezine 4

AndjelaS997, 2025-03-04:
Ocjena 4.

thewantedboss, 2025-03-04:
Ocjena 4

GeneralKenobi72, 2025-03-18:
Vrijeme izrade 40min

Closed 2025-03-18.

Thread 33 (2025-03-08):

Firmware - LED & BUTTON

thewantedboss, 2025-03-08:
Potrebno je programirati mikrokontroler tako da kontrolise upaljivanje i gasenje led diode, kao i button za funkciju reset-a.

GeneralKenobi72, 2025-03-18:
Ocjena 4

AndjelaS997, 2025-03-18:
Ocjena 5.

AndjelaS997, 2025-03-18:
Vrijeme izrade 40min.

thewantedboss, 2025-03-19:
Ocjena 2

Closed 2025-03-18.

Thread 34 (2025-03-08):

Firmware - Servo

thewantedboss, 2025-03-08:
Potrebno je programirati mikrokontroler tako da upravlja servo motorom.

AndjelaS997, 2025-03-18:
Ocjena 7.

thewantedboss, 2025-03-19:
Ocjena 7

Closed 2025-03-18.

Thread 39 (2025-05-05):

Dokumentovati firmware kod

GeneralKenobi72, 2025-05-05:
Potrebno dokumentovati:
* led modul
* button modul
* wifi modul
* color sensor modul

GeneralKenobi72, 2025-05-05:
Ocjena tezine 4

AndjelaS997, 2025-05-07:
Ocjena 5.

thewantedboss, 2025-05-07:
ocjena 6

GeneralKenobi72, 2025-05-08:
Vrijeme izrade: 4 sata

Closed 2025-05-08.

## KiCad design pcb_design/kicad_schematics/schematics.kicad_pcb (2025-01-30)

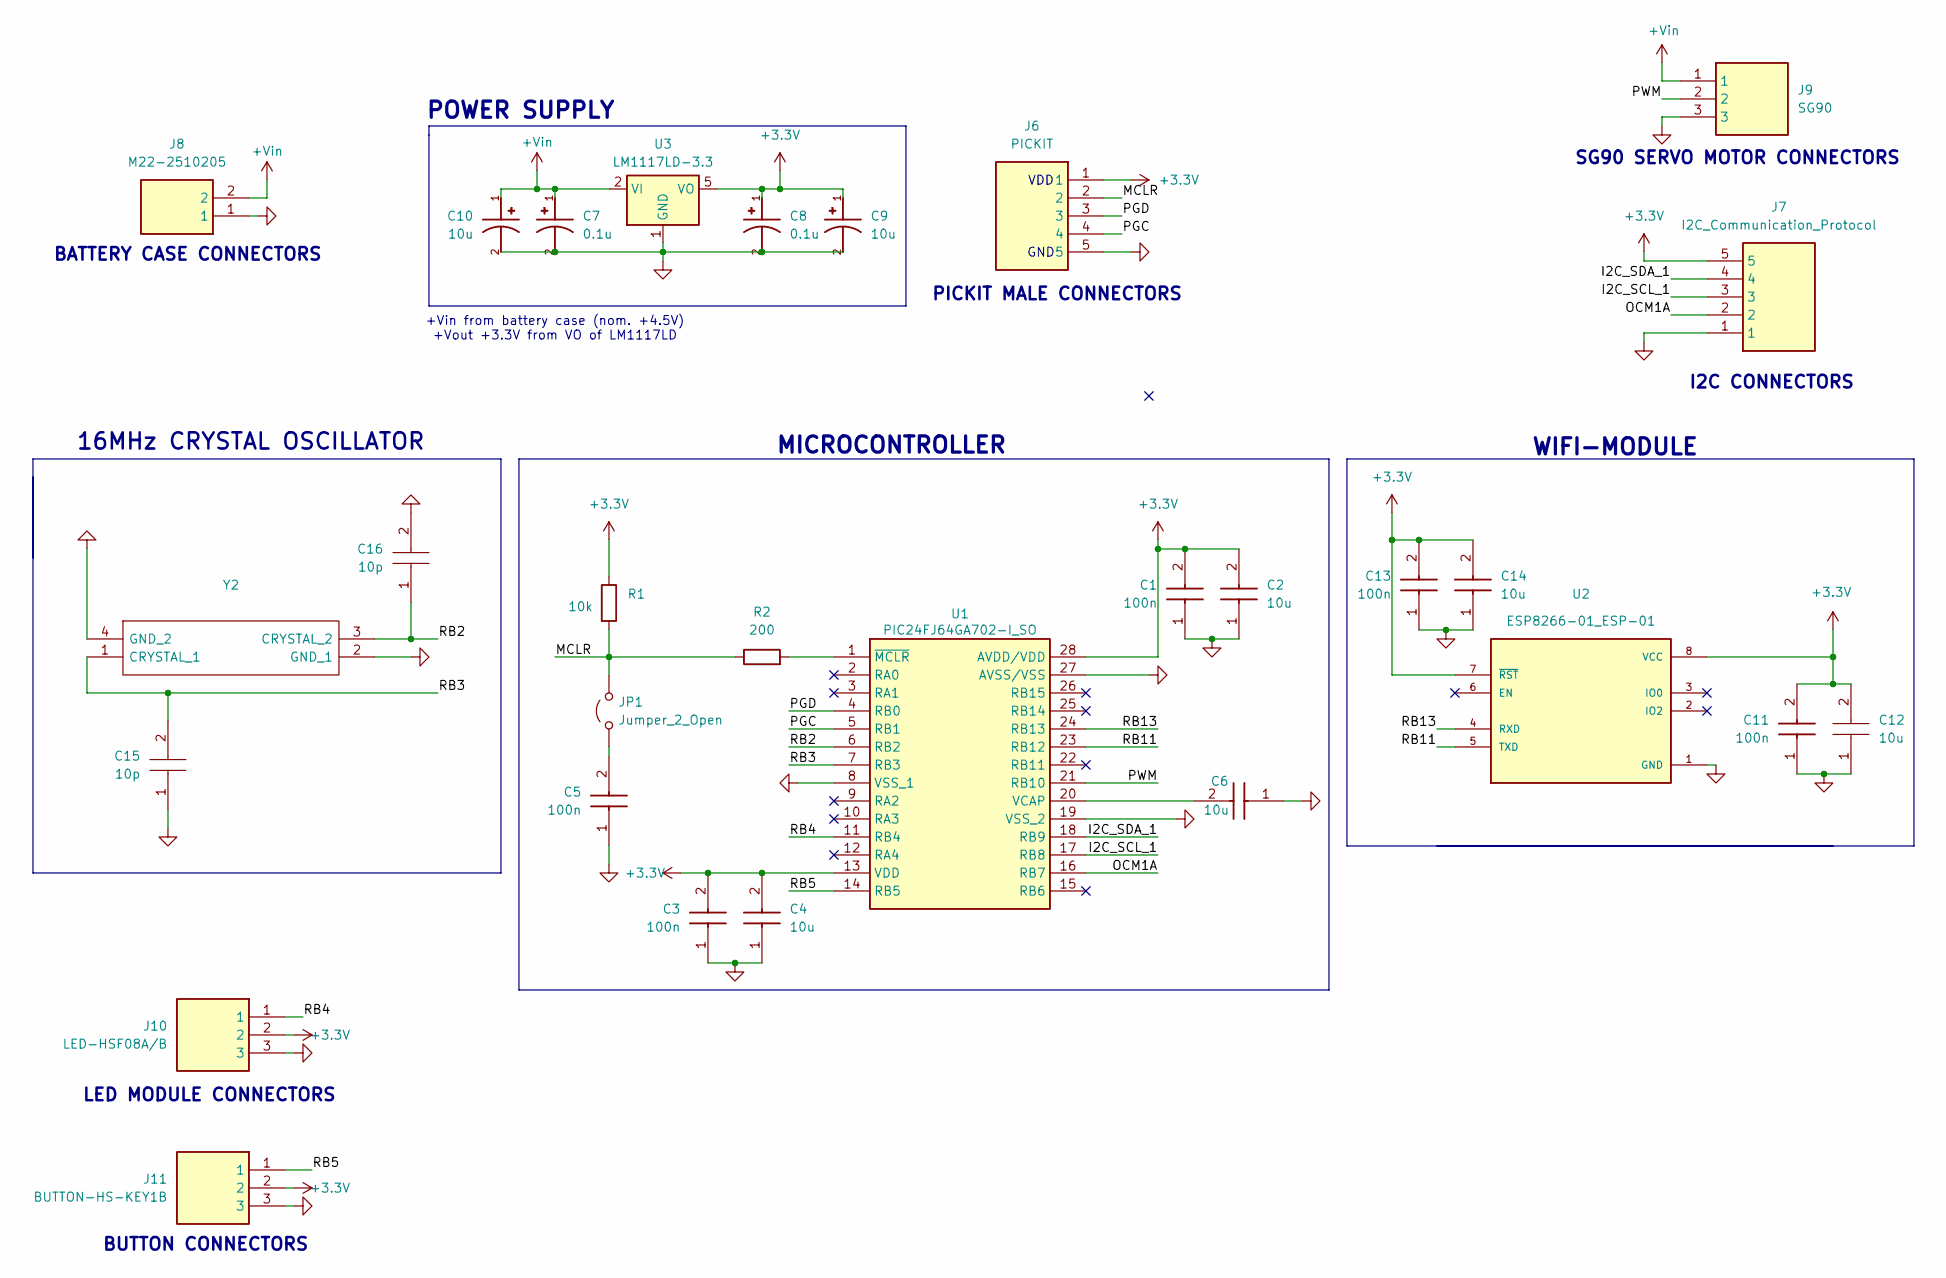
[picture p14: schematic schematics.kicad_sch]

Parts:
C1, C3, C5, C11, C13: 100n; C0402; Mouser Part Number 80-C0402C104M4P
C2, C4, C6, C12, C14: 10u; C0805; Mouser Part Number 80-C0805C106M4P
C7, C8: 0.1u; CAPAE430X550N
C9, C10: 10u; CAPPRD200W50D500H1250
C15, C16: 10p; CAPC0603X33N; Mouser Part Number 581-02013A100J
J6: PICKIT; HDRV5W64P0X254_1X5_1270X254X610P; Mouser Part Number 855-M20-9990546
J7: I2C_Communication_Protocol; HDRV5W64P0X254_1X5_1270X254X610P; Mouser Part Number 855-M20-9990546
J8: M22-2510205; HDRV2W60P0X200_1X2_400X200X525P; Mouser Part Number 855-M22-2510205
J9: SG90; HDRV3W60P0X200_1X3_600X200X525P; Mouser Part Number 855-M22-2510305
J10: LED-HSF08A/B; HDRV3W60P0X200_1X3_600X200X525P; Mouser Part Number 855-M22-2510305
J11: BUTTON-HS-KEY1B; HDRV3W60P0X200_1X3_600X200X525P; Mouser Part Number 855-M22-2510305
JP1: Jumper_2_Open; HDRV2W60P0X200_1X2_400X200X525P
R1: 10k; ERA8KEB1004V
R2: 200; RESC3216X70N
U1: PIC24FJ64GA702-I_SO; SOIC127P1030X265-28N; Mouser Part Number 579-24FJ64GA702ISO
U2: ESP8266-01_ESP-01; XCVR_ESP8266-01_ESP-01; PARTREV V1.2
U3: LM1117LD-3.3; WSON-8-1EP_4x4mm_P0.8mm_EP2.2x3mm
Y2: 16MHz crystal; 830108288709; Mouser Part Number 710-830108288709

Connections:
+3.3V: C1.2, C2.2, C3.2, C4.2, C8.1, C9.1, C11.2, C12.2, C13.2, C14.2, J6.1, J7.5, J10.2, J11.2, R1.1, U1.13 (VDD), U1.28 (AVDD/VDD), U2.7 (~RST), U2.8 (VCC), U3.5 (VO), U3.6 (VO), U3.7 (VO), U3.9 (VO); also elsewhere on the board
+Vin: C7.1, C10.1, J8.2, J9.1, U3.2 (VI), U3.3 (VI), U3.4 (VI)
/I2C_SCL_1: J7.3, U1.17 (RB8)
/I2C_SDA_1: J7.4, U1.18 (RB9)
/MCLR: J6.2, JP1.2 (B), R1.2, R2.1
/OCM1A: J7.2, U1.16 (RB7)
/PGC: J6.4, U1.5 (RB1)
/PGD: J6.3, U1.4 (RB0)
/PWM: J9.2, U1.21 (RB10)
/RB2: C16.1, U1.6 (RB2), Y2.3 (CRYSTAL_2)
/RB3: C15.2, U1.7 (RB3), Y2.1 (CRYSTAL_1)
/RB4: J10.1, U1.11 (RB4); also elsewhere on the board
/RB5: J11.1, U1.14 (RB5)
/RB11: U1.23 (RB12), U2.5 (TXD)
/RB13: U1.24 (RB13), U2.4 (RXD)
GND: C1.1, C2.1, C3.1, C4.1, C5.1, C6.1, C7.2, C8.2, C9.2, C10.2, C11.1, C12.1, C13.1, C14.1, C15.1, C16.2, J6.5, J7.1, J8.1, J9.3, J10.3, J11.3, U1.8 (VSS_1), U1.19 (VSS_2), U1.27 (AVSS/VSS), U2.1 (GND), U3.1 (GND), Y2.2 (GND_1), Y2.4 (GND_2); also elsewhere on the board
unnamed: C5.2, JP1.1 (A)
unnamed: C6.2, U1.20 (VCAP)
unnamed: R2.2, U1.1 (~MCLR)

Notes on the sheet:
MICROCONTROLLER
PICKIT MALE CONNECTORS
LED MODULE CONNECTORS
SG90 SERVO MOTOR CONNECTORS
GND
POWER SUPPLY
BUTTON CONNECTORS
BATTERY CASE CONNECTORS
+Vin from battery case (nom. +4.5V) +Vout +3.3V from VO of LM1117LD
I2C CONNECTORS
16MHz CRYSTAL OSCILLATOR
WIFI-MODULE
VDD

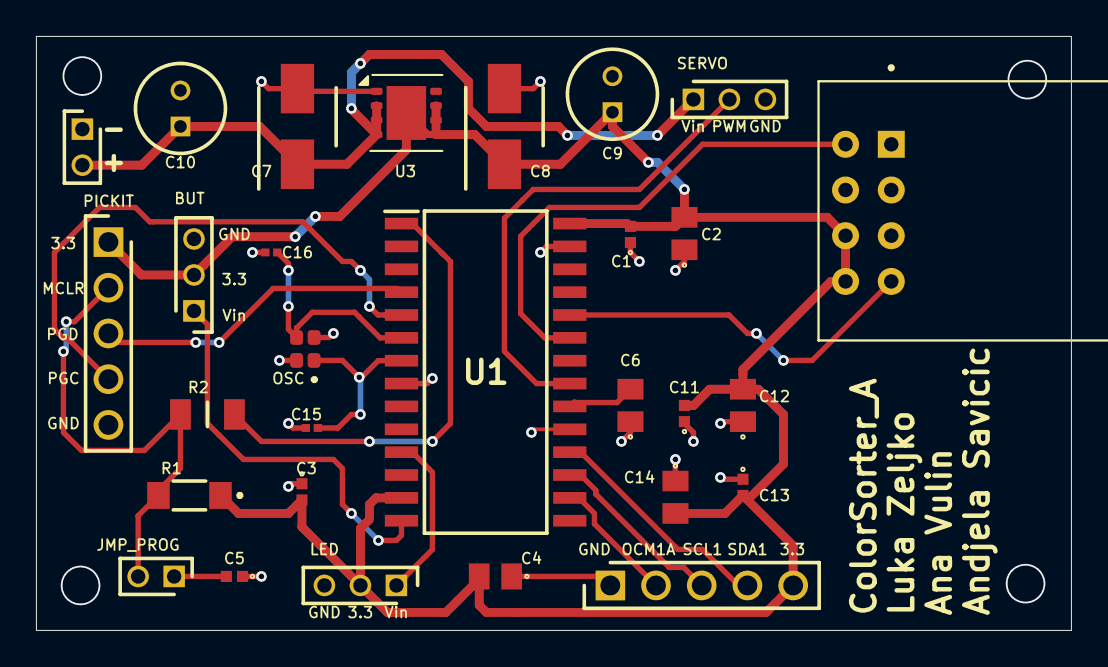
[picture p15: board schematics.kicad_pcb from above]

Board: 2 copper layers, 57.5 x 33.0 mm, 29 parts (0 on the bottom side), 19 nets.

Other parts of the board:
LED: LED-HSF08A/B; HDRV3W60P0X200_1X3_600X200X525P

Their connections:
+3.3V: LED.2; also elsewhere on the board
/RB4: LED.1; also elsewhere on the board
GND: LED.3; also elsewhere on the board

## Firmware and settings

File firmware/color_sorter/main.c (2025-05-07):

/**
 * @file main.c
 * @brief File that contains main function of project
 *
 * This file contains main function that calls initialize functions
 * of all modules needed for proper functioning of project
 */

#include "../servo/servo.h"
#include "../color_sensor/color_sensor.h"
#include "../color_sensor/i2c1_driver.h"
#include "../color_sensor/i2c_master.h"
#include "../color_sensor/i2c_simple_master.h"
#include "../color_sensor/i2c_types.h"
#include "../color_sensor/spi1.h"
#include "../led/led.h"
#include "../inc/inc.h"
#include "../wifi_module/wifi_module.h"
#include "../button/button.h"

#pragma config FNOSC = FRCPLL    // Interni oscilator
#pragma config JTAGEN = OFF   // IskljuCen JTAG
#pragma config FWDTEN = OFF   // IskljuCen Watchdog timer

void pins_init();
void INTERRUPT_Initialize (void);

int main() {
	pins_init();
    ANSA =0;
    ANSB =0;
	servo_init();
	button_init();
	wifi_init();
	led_init();
	wifi_setup_connection();

    i2c_write2ByteRegister(VEML3328_SLAVE_ADD, CONF, 0x8011);
	__delay_ms(1000);
    i2c_write2ByteRegister(VEML3328_SLAVE_ADD, CONF, 0x0430);
	__delay_ms(2000);
	__delay32(32000000);
    char* detected_color = "Nepoznata boja";
    while(1){
        if (reset_counter == 1) {
            WS2812_SetColor(128, 128, 128);
            detected_color = read_colors();
            if(strcmp(detected_color, "CRVENA")==0){
				if(color_sides[0] == 1)
					servo_right();
				else servo_left();
				wifi_send_app("000\r\n");
            }else if(strcmp(detected_color, "ZELENA")==0){
				if(color_sides[1] == 1)
					servo_right();
				else servo_left();
				wifi_send_app("111\r\n");
            }else if(strcmp(detected_color, "PLAVA")==0){
				if(color_sides[2] == 1)
					servo_right();
				else servo_left();
				wifi_send_app("222\r\n");
            }else if(strcmp(detected_color, "ZUTA")==0){
				if(color_sides[3] == 1)
					servo_right();
				else servo_left();
				wifi_send_app("333\r\n");
            }else if(strcmp(detected_color, "NARANDZASTA")==0){
				if(color_sides[4] == 1)
					servo_right();
				else servo_left();
				wifi_send_app("444\r\n");
            }else if(strcmp(detected_color, "ROZA")==0){
				if(color_sides[5] == 1)
					servo_right();
				else servo_left();
				wifi_send_app("555\r\n");
            }else if(strcmp(detected_color, "BIJELA")==0 || strcmp(detected_color, "OBIJELA")==0){
				if(color_sides[6] == 1)
					servo_right();
				else servo_left();
				wifi_send_app("666\r\n");
			}else if(strcmp(detected_color, "CRNA")==0 || strcmp(detected_color, "OCRNA")==0){
				if(color_sides[7] == 1)
					servo_right();
				else servo_left();
				wifi_send_app("777\r\n");
            }else if(strcmp(detected_color, "NO")==0){
                servo_center();
            }
            __delay_ms(400);
            servo_center();
        }else{
            __delay_ms(500);
        }
    }
}

void pins_init() {
    
    LATA = 0x0000;
    LATB = 0x0000;

    TRISBbits.TRISB8  = 1; // SCL - i2c
    TRISBbits.TRISB9  = 1; // SDA - i2c
    TRISBbits.TRISB7  = 0; // OCM1A - WS2812 communication
    TRISBbits.TRISB6  = 0; // SPI1-CLOCK
    
    //TRISA = 0x0013;
    //TRISB = 0xFF1F;

    IOCPDA = 0x0000;
    IOCPDB = 0x0000;
    IOCPUA = 0x0000;
    IOCPUB = 0x0000;

    ODCA = 0x0000;
    ODCB = 0x0000;

    ANSA = 0;//ANSA = 0x000B;
    ANSB = 0;//ANSB = 0xF00C;
   
	OSCCONbits.IOLOCK = 0;

    RPOR3bits.RP6R = 0x0008;    //RB6->SPI1:SCK1OUT
    RPOR3bits.RP7R = 0x0007;    //RB7->SPI1:SDO1
    RPINR0bits.INT1R = 5;    	//RB5->Button interrupt

	OSCCONbits.IOLOCK = 1;
    
    INTERRUPT_Initialize();
    SPI1_Initialize();
    
}
void INTERRUPT_Initialize (void)
{
    //    MICI: MI2C1 - I2C1 Master Events
    //    Priority: 1
        IPC4bits.MI2C1IP = 1;
    //    SICI: SI2C1 - I2C1 Slave Events
    //    Priority: 1
        IPC4bits.SI2C1IP = 1;
}

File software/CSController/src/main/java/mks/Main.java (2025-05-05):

/**
 * @file Main.java
 * @brief Entry point of the JavaFX desktop application for controlling microcontroller.
 *
 * This class serves as the main entry point for the JavaFX application.
 * It loads the FXML layout file, initializes the primary window (stage)
 * and sets up the graphical user interface.
 * The `start` method uses the FXMLLoader to
 * parse the `color_gui.fxml` file and obtain an instance of the `ColorGUI` controller, which handles all UI logic.
 * 
 * The static reference to the controller (`GuiInstance`) allows other parts of the application to access the UI logic if needed.
 */

package mks;

import javafx.application.*;
import javafx.fxml.*;
import javafx.scene.*;
import javafx.stage.*;
import java.io.*;
import gui.*;


public class Main extends Application{
	public static ColorGUI GuiInstance;

	public static void main(String[] args) {
		launch(args);
	}

	/**
	 * The `start` method uses the FXMLLoader to
	 * parse the `color_gui.fxml` file and obtain an
	 * instance of the `ColorGUI` controller,
	 * which handles all UI logic.
	 */
	@Override
	public void start(Stage primaryStage) throws Exception {
		String pathToFXML = "src" + File.separator + "main" + File.separator + "java" + File.separator + "gui" + File.separator + "color_gui.fxml";
		FXMLLoader loader = new FXMLLoader(new File(pathToFXML).toURI().toURL());
		Parent root = loader.load();

		Scene scene = new Scene(root);
		primaryStage.setScene(scene);
		primaryStage.setTitle("ColorSorterController");
		primaryStage.show();

		GuiInstance = loader.getController();
	}
}

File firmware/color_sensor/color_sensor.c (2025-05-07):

/**
 * @file color_sensor.c
 * @brief Color sensor module source file
 *
 * This file contains definitions of functions decleared in
 * color_sensor.h
 */

#include "color_sensor.h"
#include "../led/led.h"
#include "../inc/inc.h"
#include "../color_sensor/i2c_simple_master.h"
#include "../color_sensor/i2c_master.h"

#include "xc.h"
#include <stdio.h>
#include <math.h>
#include <stdint.h>

uint16_t sensor_value_clear;
uint16_t sensor_value_red;
uint16_t sensor_value_green;
uint16_t sensor_value_blue;

typedef struct {
    const char* name;
    uint16_t r, g, b;
} Color;

const Color colors[] = {
    {"ZELENA",     6500, 29000, 28000},
    {"PLAVA",      13800, 45100, 65500},
    {"CRVENA",    40500, 21800, 24400},
    {"ZUTA",      45000, 65535, 40500},
    {"NARANDZASTA",40700, 18800, 14500},
    {"ROZA",      34100, 20200, 29800},
    {"CRNA",       6000, 12300, 16500},
    {"BIJELA",    48900, 65535, 65535},
    {"NO",         15700,  19000,  21000},
    {"OCRNA",      7800,11800,16000}, // zeton okrenut naopacke
    {"OBIJELA",      30800,45900,63900} // zeton okrenut naopacke
};

char* detect_color(){
    
    uint16_t r = sensor_value_red;
    uint16_t g = sensor_value_green;
    uint16_t b = sensor_value_blue;

    float min_distance = 1e9; 
    const char* detected_color = "NEPOZNATA BOJA";

    for (int i = 0; i < NUM_COLORS; i++) {
        float distance = color_distance(r, g, b, colors[i].r, colors[i].g, colors[i].b);
        if (distance < min_distance) {
            min_distance = distance;
            detected_color = colors[i].name;
        }
    }

    return detected_color;
}

void WS2812_Send_Byte(uint8_t byte){
    for (int i = 7; i >= 0; i--)  
    {
        uint8_t spi_data = (byte & (1 << i)) ? 0b11110000 : 0b11000000; 
        SPI1_Exchange8bit(spi_data);
    }
}

void WS2812_SetColor(uint8_t red, uint8_t green, uint8_t blue){
  
    SPI1CON1Lbits.SPIEN = 0;
    __delay_us(50);
    SPI1CON1Lbits.SPIEN = 1;
    
    WS2812_Send_Byte(green);
    WS2812_Send_Byte(red);
    WS2812_Send_Byte(blue);
     
    SPI1CON1Lbits.SPIEN = 0;
    __delay_us(50);
    SPI1CON1Lbits.SPIEN = 1;
      
}

uint16_t VEML3328_readConfig(uint16_t r){    
    uint16_t reg = i2c_read2ByteRegister(VEML3328_SLAVE_ADD, r); 
    return ((reg & 0xFF) << 8) | (reg >> 8);
}

char* read_colors(){
    
    char buff[100];
    uint16_t values_red[NUM_SAMPLES];
    uint16_t values_green[NUM_SAMPLES];
    uint16_t values_blue[NUM_SAMPLES];

    uint32_t sum_red = 0, sum_green = 0, sum_blue = 0;
    uint16_t avg_red, avg_green, avg_blue;

    __delay_ms(1000);

    
    for (int i = 0; i < NUM_SAMPLES; i++) {
        
        sum_red += VEML3328_readConfig(R_DATA);
        sum_green += VEML3328_readConfig(G_DATA);
        sum_blue += VEML3328_readConfig(B_DATA);

        __delay_ms(100);
     
    }

    avg_red = sum_red / NUM_SAMPLES;
    avg_green = sum_green / NUM_SAMPLES;
    avg_blue = sum_blue / NUM_SAMPLES;

    sensor_value_red = avg_red;
    sensor_value_blue = avg_blue;
    sensor_value_green = avg_green;

    return detect_color();
} 

float color_distance(uint16_t r1, uint16_t g1, uint16_t b1, uint16_t r2, uint16_t g2, uint16_t b2){
    
    int32_t dr = (int32_t)r1 - (int32_t)r2;
    int32_t dg = (int32_t)g1 - (int32_t)g2;
    int32_t db = (int32_t)b1 - (int32_t)b2;
    return sqrtf(dr*dr + dg*dg + db*db);
}

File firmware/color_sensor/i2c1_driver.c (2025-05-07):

/**
 * @file i2c1_driver.c
 * @brief I2C driver source file
 *
 * This file contains definitions of functions decleared in
 * i2c1_driver.h
 */

#include <stdio.h>
#include <stdint.h>
#include <stdbool.h>
#include "i2c1_driver.h"
#include "../inc/inc.h"
#include <xc.h>

#include <libpic30.h>

void (*i2c1_driver_busCollisionISR)(void);
void (*i2c1_driver_Masteri2cISR)(void);
void (*i2c1_driver_Slavei2cISR)(void);

void i2c1_driver_close(void)
{
    I2C1CONLbits.I2CEN = 0;
}

/* Interrupt Control */
void i2c1_enableIRQ(void)
{
    IEC1bits.MI2C1IE = 1;
    IEC1bits.SI2C1IE = 1;
}

bool i2c1_IRQisEnabled(void)
{
    return IEC1bits.MI2C1IE || IEC1bits.SI2C1IE;
}

void i2c1_disableIRQ(void)
{
    IEC1bits.MI2C1IE = 0;
    IEC1bits.SI2C1IE = 0;
}

void i2c1_clearIRQ(void)
{
    IFS1bits.MI2C1IF = 0;
    IFS1bits.SI2C1IF = 0;
}

void i2c1_setIRQ(void)
{
    IFS1bits.MI2C1IF = 1;
    IFS1bits.SI2C1IF = 1;
}

void i2c1_waitForEvent(uint16_t *timeout)
{
    //uint16_t to = (timeout!=NULL)?*timeout:100;
    //to <<= 8;
    if((IFS1bits.MI2C1IF == 0) && (IFS1bits.SI2C1IF == 0))
    {
        while(1)// to--)
        {
            if(IFS1bits.MI2C1IF || IFS1bits.SI2C1IF) break;
            __delay_us(100);
        }
    }
}

bool i2c1_driver_driver_open(void)
{
    if(!I2C1CONLbits.I2CEN)
    {
        // initialize the hardware
        // STAT Setting 
        I2C1STAT = 0x0;
        
        // CON Setting
        I2C1CONL = 0x8000;
        
        // Baud Rate Generator Value: I2CBRG 100000;   
        I2C1BRG = 78;
        
        return true;
    }
    else
        return false;
}
bool i2c1_driver_initSlaveHardware(void)
{
    if(!I2C1CONLbits.I2CEN)
    {
        I2C1CONHbits.AHEN = 1;
        I2C1CONHbits.DHEN = 1;
        I2C1CONLbits.STREN = 1;
        
        I2C1CONLbits.I2CEN = 1;
        return true;
    }
    return false;
}

void i2c1_driver_resetBus(void)
{
    
}

void i2c1_driver_start(void)
{
    I2C1CONLbits.SEN = 1;
}

void i2c1_driver_restart(void)
{
    I2C1CONLbits.RSEN = 1;
}

void i2c1_driver_stop(void)
{
    I2C1CONLbits.PEN = 1;
}

bool i2c1_driver_isNACK(void)
{
    return I2C1STATbits.ACKSTAT;
}

void i2c1_driver_startRX(void)
{
    I2C1CONLbits.RCEN = 1;
}

char i2c1_driver_getRXData(void)
{
    return I2C1RCV;
}

void i2c1_driver_TXData(uint8_t d)
{
    I2C1TRN = d;
}

void i2c1_driver_sendACK(void)
{
    I2C1CONLbits.ACKDT = 0;
    I2C1CONLbits.ACKEN = 1; // start the ACK/NACK
}

void i2c1_driver_sendNACK(void)
{
    I2C1CONLbits.ACKDT = 1;
    I2C1CONLbits.ACKEN = 1; // start the ACK/NACK
}

void i2c1_driver_releaseClock(void)
{
    I2C1CONLbits.SCLREL = 1;
}

bool i2c1_driver_isBuferFull(void)
{
    return I2C1STATbits.RBF || I2C1STATbits.TBF;
}

bool i2c1_driver_isStart(void)
{
    return I2C1STATbits.S;
}

bool i2c1_driver_isAddress(void)
{
    return !I2C1STATbits.D_A;
}

bool i2c1_driver_isStop(void)
{
    return I2C1STATbits.P;
}

bool i2c1_driver_isData(void)
{
    return I2C1STATbits.D_A;
}

bool i2c1_driver_isRead(void)
{
    return I2C1STATbits.R_W;
}

void i2c1_driver_clearBusCollision(void)
{
    I2C1STATbits.BCL = 0; // clear the bus collision.
}

void i2c1_driver_enableStartIRQ(void)
{
    I2C1CONHbits.SCIE = 1;
}

void i2c1_driver_disableStartIRQ(void)
{
    I2C1CONHbits.SCIE = 0;
}

void i2c1_driver_enableStopIRQ(void)
{
    I2C1CONHbits.PCIE = 1;
}

void i2c1_driver_disableStopIRQ(void)
{
    I2C1CONHbits.PCIE = 0;
}

void i2c1_driver_setBusCollisionISR(interruptHandler handler){
    i2c1_driver_busCollisionISR = handler;
}

void i2c1_driver_setMasterI2cISR(interruptHandler handler){
    i2c1_driver_Masteri2cISR = handler;
}

void i2c1_driver_setSlaveI2cISR(interruptHandler handler){
    i2c1_driver_Slavei2cISR = handler;
}



/**
 * @brief Interrupt service routine for I2C1 master interrupt.
 *
 * This interrupt handler is called when an I2C1 master mode interrupt occurs. It invokes
 * the user-defined ISR set by the `i2c1_driver_setMasterI2cISR` function.
 */
void __attribute__ ( ( interrupt, no_auto_psv ) ) _MI2C1Interrupt ( void )
{
    (*i2c1_driver_Masteri2cISR)();
}

/**
 * @brief Interrupt service routine for I2C1 slave interrupt.
 *
 * This interrupt handler is called when an I2C1 slave mode interrupt occurs. It invokes
 * the user-defined ISR set by the `i2c1_driver_setSlaveI2cISR` function.
 */
void __attribute__ ( ( interrupt, no_auto_psv ) ) _SI2C1Interrupt ( void )
{
    (*i2c1_driver_Slavei2cISR)();
}

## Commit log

2024-11-29 Minimalna konfiguracija mikorkontrolera u kicadu
    [schematics.kicad_sch]
2024-12-02 Dodani odgovarajuci kondezatori u schematics.
    [schematics.kicad_sch]
2024-12-03 Dodane vrijednosti ostalih otpornika i kondenzatora u minimalnoj konf
    [schematics.kicad_sch]
2024-12-03 Wi-Fi modul dodan u KiCAD
    [schematics.kicad_sch]
2024-12-09 #16 Dokumentovani modul Color 10 Click(RGB senzor) dodati u KiCad semu Izvuceni su pinovi I2C i pin za DI komunikacije
    [schematics.kicad_sch]
2024-12-11 obrisani nepotrebni fajlovi
    [schematics_3.kicad_sch]
2024-12-11 Dodatak za gitignore
    [schematics.kicad_sch]
2024-12-11 ICSP pinovi
    [schematics.kicad_sch]
2024-12-11 Dodani modeli koristeni u KiCAD-u
    [ESP8266-01_ESP-01.STEP, ESP8266-01_ESP-01.step]
2024-12-11 #11 Analiza power supply šeme Dodan je lin. regulator u semi
    [schematics.kicad_sch]
2024-12-11 Dodajem modele X5R capacitors koji su korišćeni u šemi
    [6130XX11821_61300811821.step, schematics.kicad_sch]
2024-12-13 Komentari sastanka
    [schematics.kicad_sch]
2024-12-18 Dodani decoupling kondenzatori kod wifi modula i regulatora
    [schematics.kicad_sch]
2024-12-18 Dodan eksterni oscilator
    [ESP8266-01_ESP-01.STEP, ESP8266-01_ESP-01.step, schematics.kicad_sch]
2024-12-28 Dodani pin headers i odgovarajući modeli koji se koriste u šemi
    [T495B106K025ATE750.step, schematics.kicad_sch]
2024-12-29 Uredjena šema sa dodanim pin konektorima.
2025-01-13 13.1.25, dodani footprinti i inicijalna sema pcba
    [6130XX11821_61300811821.step, schematics.kicad_pcb, schematics.kicad_sch]
2025-01-15 Prva verzija pcb.
    [schematics.kicad_pcb, schematics.kicad_sch]
2025-01-23 Inicijalno rutiranje, dodani i neki 3d modeli
    [830108288709.stp, C0805C106M4PACTU.stp, PIC24FJ64GA702-I_SO.stp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]
2025-01-25 Dodani modeli ostalih komponenata u models, Podebljane zice koje nose napajanje, wifi modul okrenut, dodane oznake elemenata
    [02013A100JAT2A.stp, C0402C104M4PACTU.stp, C0805C106M4PACTU.stp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]
2025-01-29 Ispravljene greske sa sastanka
    [schematics.kicad_pcb]
2025-01-29 Ispravljen warning
    [schematics.kicad_pcb]
2025-01-30 Promijenjeni simboli nekih komponenti
    [schematics.kicad_sch]
2025-01-30 promjena C5.
    [schematics.kicad_sch]
2025-01-30 Povecan font imena inzenjera
    [schematics.kicad_pcb]
2025-01-30 Dodajem gotovu listu komponenata.
    [tabela sa komponentama_1.xlsx]
2025-01-30 Dodane rupe u coskove pcb-a za sarafljenje
    [schematics.kicad_pcb]
2025-01-30 Dodan mikrokontroler komponenta u listu materijala.
    [tabela sa komponentama_1.xlsx]
2025-03-18 Dodani gerber fajlovi
    [schematics-B_Cu.gbl, schematics-B_Mask.gbs, schematics-B_Paste.gbp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]
2025-03-18 Popravljan i2c
2025-03-19 Testiranje I2C
2025-04-02 Dodani u inc.h potrebni define
    [tabela sa komponentama_1.xlsx]
2025-04-02 Prilagodjen servo motor novoj frekvenciji
2025-04-04 Dodana prekidana rutina za reset pritiskom dugmeta.
    [color_sensor.c]
2025-04-05 Integrisani color click i servo motor, rade skupa
2025-04-12 Na pritisak misom na all left dugme u user app natjeran servo motor da se pomjeri u desno
2025-04-12 Na pritisak lijevog dugmeta u app, servo lijevo, na pritisak desnog, servo desno
2025-04-14 Uklonjeno koristenje uart1 kanala od strane color sensora, start stop omoguceni iz korisnicke aplikacije
2025-05-07 Dokumentacija coloe sensora i i2c funckija koje se koriste
2025-05-07 Dokumentacija za button.
2025-05-07 Dodane dokumentacije main.c fajla, servoa i ostale dopunjene
2025-05-11 izmijena u button-u.
